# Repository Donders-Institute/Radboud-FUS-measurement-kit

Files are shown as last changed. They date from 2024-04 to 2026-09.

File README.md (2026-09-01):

# Radboud FUS measurement kit

<div align="center">
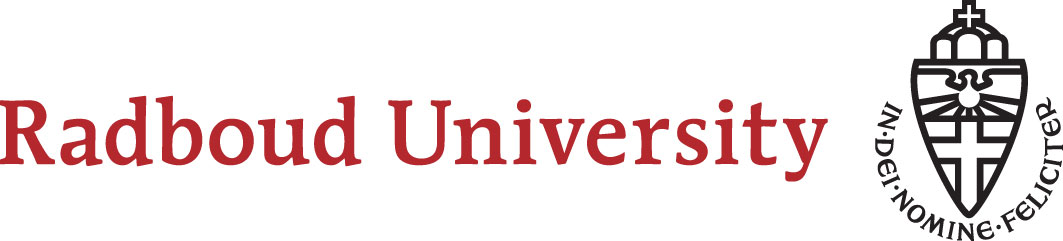
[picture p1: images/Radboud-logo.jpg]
ru_logo
  

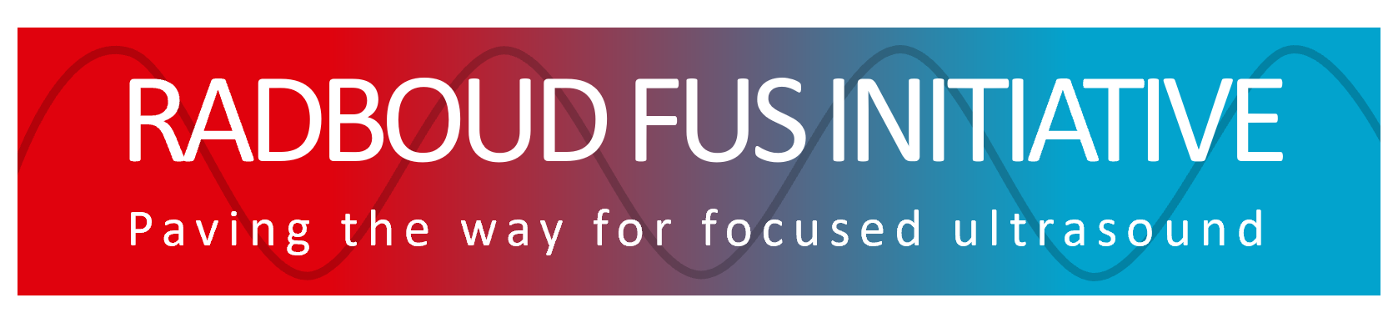
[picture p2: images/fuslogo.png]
fus_logo
  

  igt_logo
  
</div>

https://github.com/user-attachments/assets/676b7667-6fb5-469c-bd78-fa9b3e943115

<div align="center">
  
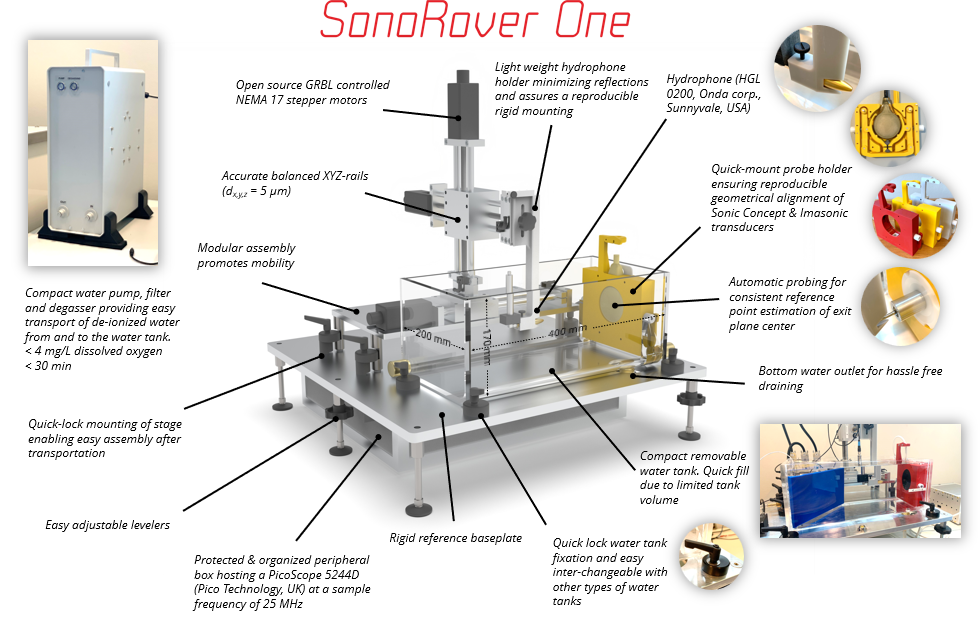
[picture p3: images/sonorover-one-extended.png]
sonorover-one
  
  
</div>

<!-- TABLE OF CONTENTS -->

# 📗 Table of Contents

- [📖 About the Project](#about-project)
  - [🚀 Key Features](#key-features)
  - [👥 Authors](#authors)
  - [✒️ How to cite](#how-to-cite)
- [💻 Getting Started](#getting-started)
  - [🔧 Installation](#install)
  - [🔌 Compatibility](#comp)
  - [📋 Usage](#usage)
- [📊 Data Analysis](#data-analysis)
- [🧰 Configuration](#config)
  - [⚙ Main Configuration File](#main-config)
  - [📻 How to add your own equipment](#add-equip)
- [🔭 Future Features](#future-features)
- [🤝 Contributing](#contributing)
- [📝 License](#license)

<!-- PROJECT DESCRIPTION -->

# 📖 Radboud FUS measurement kit 

(Project id: **0003429**)

**Radboud FUS measurement kit** is a comprehensive kit allowing precise hydrophone measurements of your TUS transducers for verification, characterization and monitoring overall system performance.    

This project is facilitated by the Radboud Focused Ultrasound Initiative. For more information, please visit the [website](https://www.ru.nl/en/donders-institute/research/research-facilities/focused-ultrasound-initiative-fus).

**⚠️ DEVELOPMENT STATUS**: This repository is currently under active development and is provided AS IS. Features may be incomplete, undergo significant changes, or contain bugs. Use at your own discretion.

<!-- Features -->

## 🚀 Key Features 

- **Comprehensive Measurement Solution:** Complete hardware and software package for ultrasound field characterization
- **High Precision Hydrophone Measurements:** Accurate characterization of acoustic parameters and beam profiles
- **Modular, Extensible Architecture:** Easily add new equipment with standardized interfaces
- **Seamless Hardware Integration:** Compatible with multiple driving systems, transducers, and measurement devices
- **Automated Acoustical Alignment:** Precise determination of the acoustical axis for optimal measurements
- **Open-Source Software:** Fully transparent, customizable codebase with no licensing costs
- **Complementary Data Analysis Tools:** Export and analyze measurement data with included utilities

<p align="right">(<a href="#readme-top">back to top</a>)</p>

<!-- AUTHORS -->

## 👥 Authors 

👤 **[Margely Cornelissen](https://www.ru.nl/en/people/cornelissen-m), [FUS Centre](https://www.ru.nl/en/donders-institute/research/research-facilities/focused-ultrasound-initiative-fus), Radboud University**

- GitHub: [@MaCuinea](https://github.com/MaCuinea)
- [LinkedIn](https://linkedin.com/in/margely-cornelissen)

👤 **[Stein Fekkes](https://www.ru.nl/en/people/fekkes-s), [FUS Centre](https://www.ru.nl/en/donders-institute/research/research-facilities/focused-ultrasound-initiative-fus), Radboud University**

- GitHub: [@StefFek-GIT](https://github.com/StefFek-GIT)
- [LinkedIn](https://linkedin.com/in/sfekkes)

👤 **Erik Dumont, [Image Guided Therapy (IGT)](http://www.imageguidedtherapy.com/)**
- GitHub: [@erikdumontigt](https://github.com/erikdumontigt)
- [LinkedIn](https://linkedin.com/in/erik-dumont-986a814)

👤 **Twan de Bruin, Technical Support Group, Donders Centre for Cognition, Radboud University**

👤 **Sibrecht Bouwstra, Technical Support Group, Donders Centre for Cognition, Radboud University**

👤 **Jan Menssen, Medical Ultrasound Imaging Center, Radboud University Medical Center**

👤 **Norbert Hermesdorf, Technical Support Group, Donders Centre for Cognition, Radboud University**

👤 **Eleanor Martin, Department of Medical Physics and Biomedical Engineering, University College London**

👤 **Lennart Verhagen, [FUS Centre](https://www.ru.nl/en/donders-institute/research/research-facilities/focused-ultrasound-initiative-fus), Radboud University**

<p align="right">(<a href="#readme-top">back to top</a>)</p>

## ✒️ How to cite 

If you use this kit in your research or project, please cite it as follows:

Margely Cornelissen, Stein Fekkes, Erik Dumont, Twan de Bruin, Sibrecht Bouwstra, Jan Menssen, Norbert Hermesdorf, Eleanor Martin & Lennart Verhagen (2024-2026), Radboud FUS measurement kit (version 1.3), https://doi.org/10.17605/OSF.IO/CG3AQ

<p align="right">(<a href="#readme-top">back to top</a>)</p>

<!-- GETTING STARTED -->

# 💻 Getting Started 

## 🔧 Installation 

### Hardware

The hardware files are stored as native solidworks files and as step format. The main assembly file: W0003510-00-01-SonoRover One.SLDASM will contain all references to part files and subassemblies. For detailed assembly instructions, refer to the [Setup Manual](/SonoRover%20One/hardware/Documentation/SonoRover%20One%20Setup%20manual%20V0_8.pdf).

### Software

#### System Architecture

Before diving into the installation, it is helpful to understand how the SonoRover One software is structured. The SonoRover One software is built on top of the standardized [Radboud FUS driving system software package](https://github.com/Donders-Institute/Radboud-FUS-driving-system-software). 

<br /> 
<div align="center">
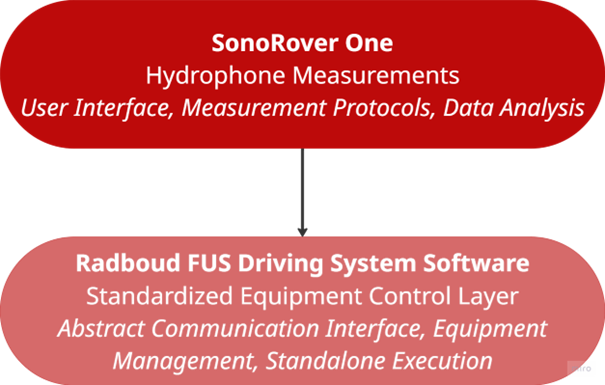
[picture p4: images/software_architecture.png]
Software Architecture
  
</div>

<br /> 

This modular approach provides:

- **Equipment Flexibility**: Easily incorporate new equipment with different communication protocols
- **Centralized Updates**: Core driving functionality can be updated independently
- **Consistent Interface**: Uniform interaction with diverse hardware components
- **Dual-Use Capability**: The same equipment configurations work in both standalone experiments and hydrophone measurements

#### Important Note

**This package is developed specifically for Windows operating systems.** While it might work in other environments with some modifications, full support is provided only for Windows.

#### Installation Steps

1. **Clone the Repository**\
   You can clone this repository using either:

   - **Git Terminal**
     ```sh
     cd my-folder
     git clone git@github.com:Donders-Institute/Radboud-FUS-measurement-kit.git
     ```

   - **GitHub Desktop**
     1. Click on 'Current repository'
     2. Click on 'Add' and select 'Clone repository...'
     3. Choose 'URL' and paste the following repository URL: [https://github.com/Donders-Institute/Radboud-FUS-measurement-kit.git](https://github.com/Donders-Institute/Radboud-FUS-measurement-kit.git)
     4. Choose your desired folder and clone the repository

2. **Download Python 3.10**\
Ensure you have Python 3.10 installed and accessible from your command line. If Python is not installed, download it from the [official Python website](https://www.python.org/downloads/release/python-31011/). It is not necessary to add Python to your system's PATH during installation, as virtual environments allow you to manage and switch between Python versions without affecting other projects or code outside the environment.

	<br /> 
	<div align="center">
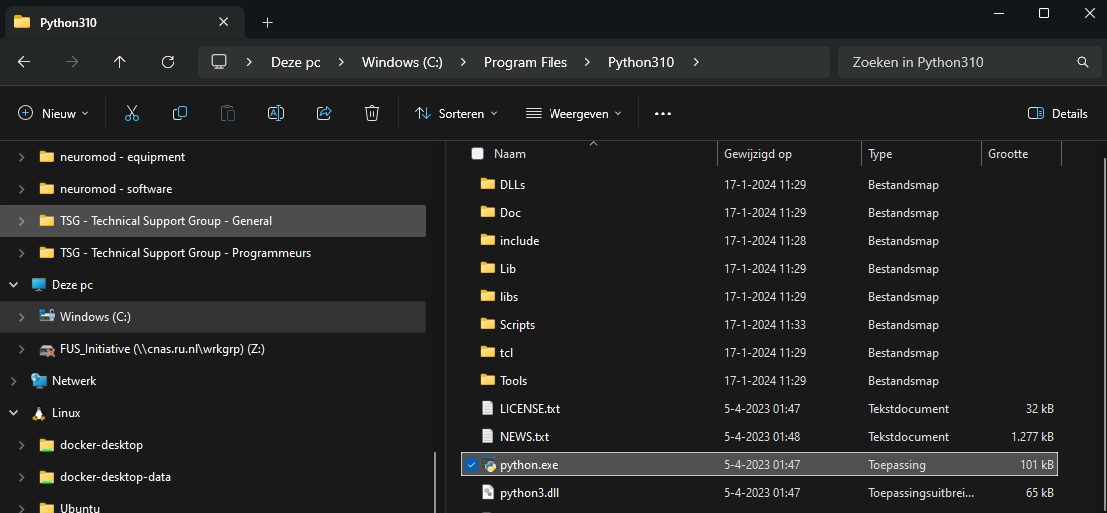
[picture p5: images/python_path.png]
python_path
	  
	</div>
	
	<br /> 

	**Note**: The script assumes that Python 3.10 is installed. If you have a different version, make sure to adjust the script accordingly or install Python 3.10.

3. **Create and setup a virtual environment**\
Open your command prompt and run the following batch file to set up the virtual environment and install the necessary dependencies. You can use input parameters to customize the environment name or directory, or Python interpreter location. You can use the default values or specify only the parameters you need by leaving others blank with "".

	```
	cd your_directory_with_cloned_repository
	create_venv.bat "[PYTHON_INTERPRETER_PATH]" [VENV_NAME] "[VENV_DIR]"
	```
		
	- PYTHON_INTERPRETER_PATH: Specify the path to the Python 3.10 interpreter if it is not in the default location. For example, C:\Path\To\Python310\python.exe.
	- VENV_NAME: Specify the name for the virtual environment (e.g., MyEnv). If not provided, it defaults to SONOROVER_ONE.
	- VENV_DIR: Specify the directory for the virtual environment (e.g., C:/Users/Me/Envs). If not provided, it defaults to C:/Users/{USERPROFILE}/Envs.
	
	Example:
	```
	create_venv.bat "C:\Path\To\Python310\python.exe" SONOROVER_ONE "C:/Users/Me/Envs"
	```

	The batch file will:
	- Create a virtual environment
	- Install the required Python packages and the default IDE, Spyder
	- Clone the Radboud FUS driving system software repository into the SonoRover One repository. **Note:** The installation script automatically clones the latest released version of the Radboud FUS driving system software. If you need a different version (e.g., development branch or specific release), please refer to the [Radboud FUS driving system software README](https://github.com/Donders-Institute/Radboud-FUS-driving-system-software/blob/release/README.md) for manual installation instructions.
	- Install the Radboud FUS driving system software package

4. **Verify Installation**\
After running the batch file, ensure that the virtual environment and dependencies are installed. You can verify this by:

	- Checking for the virtual environment folder in your VENV_DIR directory.
		<div align="left">
		  verify_venv
		</div>
	
	- Confirming that the fus_driving_systems package is installed in the virtual environment site-packages folder: VENV_DIR/VENV_NAME/Lib/site-packages/.
		<div align="center">
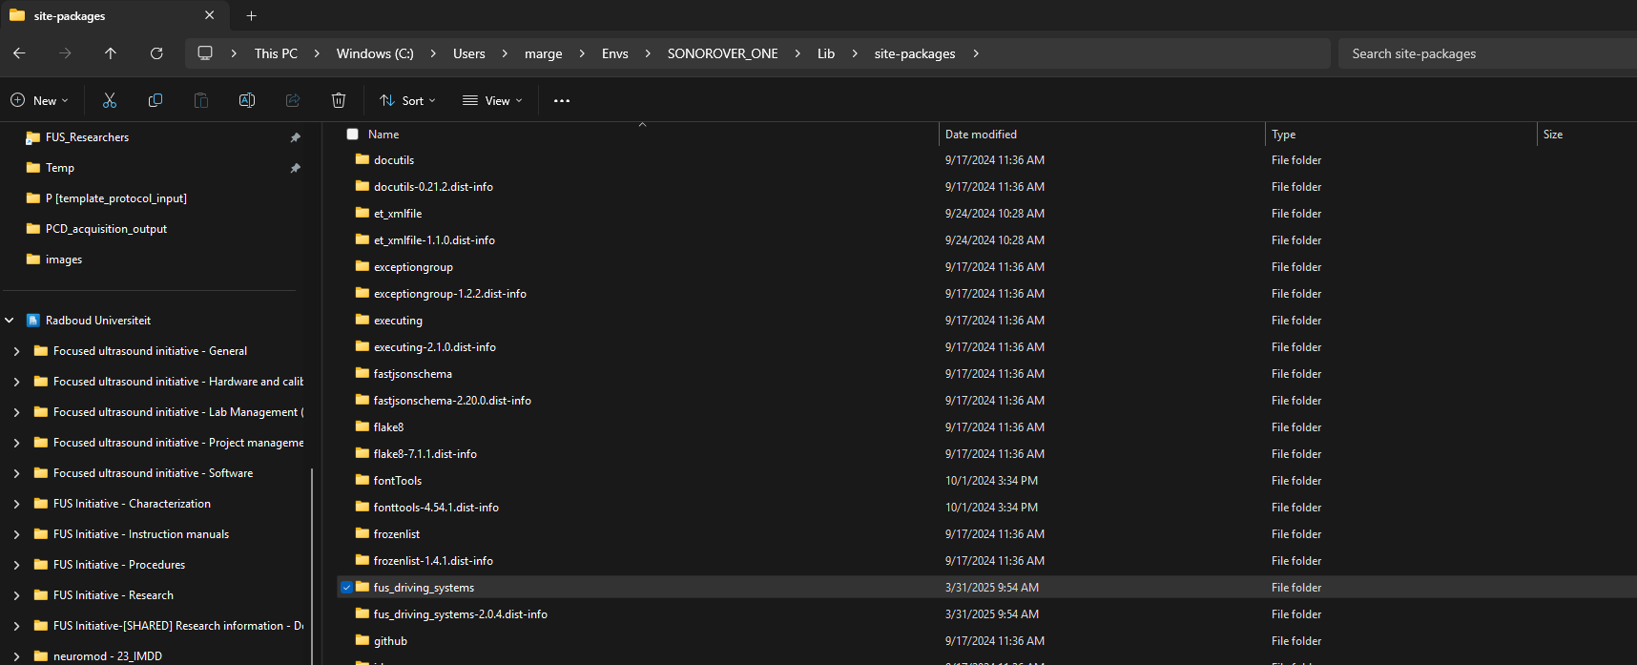
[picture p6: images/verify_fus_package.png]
verify_fus_package
		  
		</div>

#### Troubleshooting
If you encounter issues with the batch file not being recognized or errors during execution, ensure that:

- The batch file has the correct permissions to execute.
- The repository has been cloned correctly and contains the necessary files.

<p align="right">(<a href="#readme-top">back to top</a>)</p>

## 🔌 Compatibility 

The table below outlines compatibility between different versions of the Radboud FUS driving system software and the SonoRover One software.

| SonoRover One Version | Radboud FDS Compatibility | Python Version |
|---|---|---|
| 1.2 (Current) | Radboud FDS v2.1 | 3.10  |
| 1.3 (Current) | Radboud FDS v2.2+ | 3.10  |

Note:
- Newest version is **not compatible** with Radboud FDS v2.1 or lower  
- Tested with **Python 3.10**

<p align="right">(<a href="#readme-top">back to top</a>)</p>

## 📋 Usage 

### Hardware
For usage instructions, refer to paragraph 3.2 *Pre-measurement setup instructions* of the [Setup Manual](/SonoRover%20One/hardware/Documentation/SonoRover%20One%20Setup%20manual%20V0_8.pdf).

### Software

*Step 1: Activate your environment*\
With all dependencies installed, activate your environment in your command prompt. 

```
call [VENV_PATH]\Scripts\activate
```

*Step 2: Install an IDE*\
While your virtual environment is activated, you can install any IDE of your choice. Spyder is pre-installed by default. To install another IDE, run:

```
pip install [IDE]
```

*Step 3: Launch the IDE*\
After installing your IDE, you can launch it directly from the command line while the virtual environment is activated. For Spyder, enter:

```
spyder
```

#### Activate your virtual environment and launch the IDE at once
To simplify the process of activating the virtual environment and launching your IDE, you can use the provided [batch script](start_venv_and_ide.bat).

How to use the script:
1. Ensure that start_env_and_ide.bat is located in a convenient location, such as the root directory of your project or your desktop.
2. Run the script in one of the following ways:
	- Open start_venv_and_ide.bat in a text editor and modify the VENV_PATH and IDE variables directly if you prefer not to use command-line arguments. To run the .bat file, just double-click it.
	- Using the command prompt:
		```
		start_venv_and_ide.bat [VENV_PATH] [IDE]
		```
		- VENV_PATH: Specify the path to the virtual environment (e.g., C:/Users/Me/Envs/MyEnv). If not provided, it defaults to C:/Users/{USERPROFILE}/Envs/SONOROVER_ONE.
		- IDE: Specify the python interpreter. If not provided, it defaults to spyder.

#### Starting the Software
The SonoRover One software provides a graphical interface for hydrophone measurements. This section guides you through using the software.

The primary script is [main](/SonoRover%20One/software/src/main.py). Running this script launches the main GUI:

<div align="left">
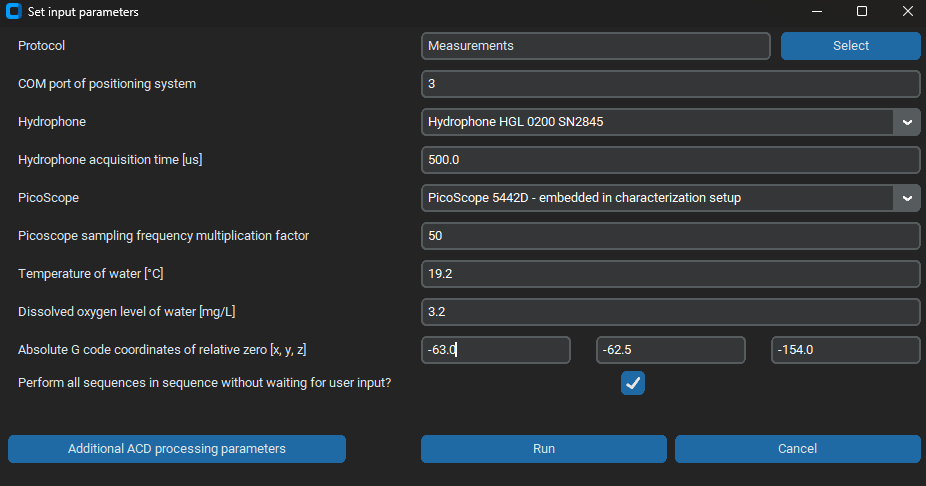
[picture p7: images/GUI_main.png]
gui_main
  
</div>

##### Main GUI Parameters

The main interface allows you to configure the following parameters:

1. **Protocol**: Opens a dialog to select a measurement protocol
2. **COM port of positioning system**: Select the communication port for the positioning system
3. **Hydrophone**: Select the hydrophone model to use for measurements
4. **Hydrophone acquisition time [us]**: Set the signal acquisition duration per grid point
5. **PicoScope**: Select the PicoScope model for signal acquisition
6. **Picoscope sampling frequency multiplication factor**: Set the sampling rate (minimum factor is 2)
7. **Temperature of water [C]**: Record water temperature for post-processing
8. **Dissolved oxygen level of water [mg/L]**: Record for documentation purposes
9. **Absolute G code coordinates of relative zero**: Set coordinates for the reference zero point. This initially uses the mechanical alignment coordinates as its basis. After completing an acoustical alignment, the system updates the x- and y-coordinates to match the measured acoustical axis at the specified z-coordinate.
10. **Perform all protocols in sequence without waiting for user input?**: Toggle automatic sequence execution

##### Protocol Selection

When you click the "Select" button, a dialog appears with system setup parameters:

- **US Driving System**: Select the ultrasound system
- **COM port of US driving system**: Required for Sonic Concepts systems
- **Transducer**: Select the transducer model
- **Operating frequency [kHz]**: Set the operating frequency of the transducer

After setting these general parameters, you have to choose between two protocol options:

*Option 1: Select Protocol Excel File*

<div align="left">
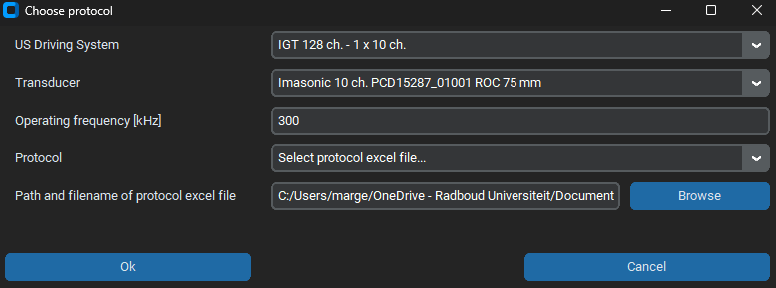
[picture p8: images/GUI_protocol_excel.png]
gui_protocol_excel
  
</div>

This option allows you to select an Excel file containing predefined measurement protocols.
- **Path and filename of protocol excel file**: Select the Excel file containing measurement protocols
  - Template available [here](SonoRover%20One/software/example%20input/protocol%20template/template_protocol_input.xlsx)
  - **Note**: If you modify column headers in the Excel file, update the corresponding settings in the configuration file

The protocol Excel file contains the following parameters for each sequence:

| Parameter | Description |
|---|---|
| **Sequence number** | Sequential number (1 to N) |
| **Tag** | Additional information saved in output .ini file |
| **Modulation** | Select from Rectangular - no ramping, Linear, or Tukey ramp shapes |
| **Ramp duration [us]** | Duration of the ramp |
| **Pulse duration [us]** | Duration of each pulse |
| **Pulse Repetition Interval [ms]** | Total pulse period including ramping, pulse duration and off-time between two pulses |
| **Power parameter** | Select appropriate power parameter for your system:<br>- IGT: Amplitude [%], Voltage [V], or Max. pressure [MPa]<br>- Sonic Concepts: Global power [mW] |
| **Corresponding value** | Value for the selected power parameter |
| **Focus definition** | Define focus relative to exit plane or mid bowl |
| **Corresponding value** | Value for the selected focus parameter |
| **(De)phase array [degree]** | For IGT systems only: option to create sham conditions |
| **Coordinates source** | Choose between coordinate Excel file or parameter-defined grid |

If using a **coordinate Excel file**:
- Provide path to the file (examples [here](SonoRover%20One/software/example%20input/coordinate%20templates))
- Allows flexible grid point arrangement
- **Note**: Headers must match configuration settings

If using **parameters**:
- **max. ± x/y/z [mm]**: Maximum movement in each direction relative to zero point
- **direction_slices/rows/columns**: Direction settings (refer to [template](SonoRover%20One/software/example%20input/protocol%20template/template_protocol_input.xlsx))
- **step_size_x/y/z [mm]**: Grid size in each direction

*Option 2: Acoustical Alignment*

<div align="left">
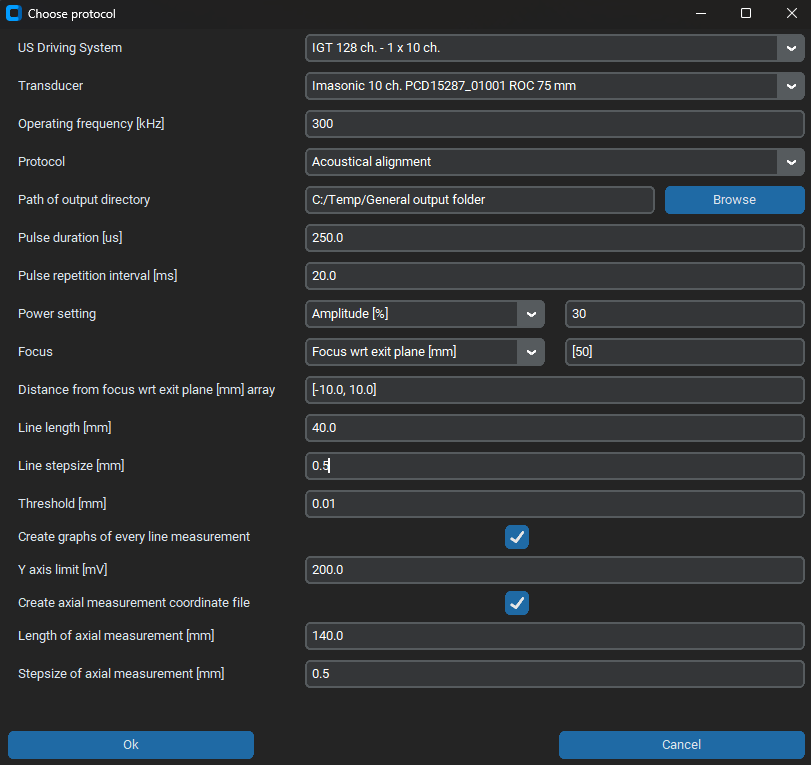
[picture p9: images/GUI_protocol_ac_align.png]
gui_protocol_ac_align
  
</div>

<br />

This option performs an acoustical alignment to determine the acoustical axis through iterative measurements. The process finds the center of mass of RMS voltage values per defined location and calculates the direction vector with corresponding azimuth and elevation.

Parameters include:

| Parameter | Description |
|---|---|
| **Path of output directory** | Directory for saving output and logging files |
| **Pulse duration [us]** | Duration of each pulse |
| **Pulse Repetition Interval [ms]** | Total pulse period including ramping, pulse duration and off-time between two pulses |
| **Power setting** | Appropriate power parameter for your system |
| **Focus** | Define focus relative to exit plane or mid bowl |
| **Distance from focus wrt exit plane [mm] array** | Distances from the focus wrt exit plane to acquire middle points (negative = toward transducer) |
| **Line length [mm]** | Length of each direction scan |
| **Line stepsize [mm]** | Step size of direction scan |
| **Threshold [mm]** | Convergence threshold for determining middle points |
| **Create graphs** | Toggle creation of direction scan graphs |
| **Y axis limit [mV]** | Y-axis limit for RMS value display |
| **Create axial measurement file** | Toggle creation of coordinate file for axial scan |
| **Length of axial measurement [mm]** | Define length for axial scan |
| **Stepsize of axial measurement [mm]** | Define step size for axial scan |

**Note:** The coordinate file generated by the acoustical alignment can be used as input for a subsequent measurement. This allows you to perform an axial scan along the precisely determined acoustical axis, rather than along a mechanically aligned axis.

#### Running Measurements

After configuring all parameters, click "OK" to start the characterization process. The software will:

1. Display dialog screens to verify equipment connections
2. Create log files in the same directory as the protocol file
3. Create an output folder for measurement results
4. Begin the measurement sequence

If you selected "Perform all protocols in sequence without waiting for user input," the software will automatically proceed through all sequences defined in the protocol file.

#### Important Notes

- When performing acoustical alignment, the found X and Y values will overwrite the initial absolute G code coordinates
- Ensure the PicoScope software is not connected to the PicoScope during measurements
- Ensure Universal Gcode Sender is not connected to the positioning system

<p align="right">(<a href="#readme-top">back to top</a>)</p>

# 📊 Data Analysis 

For usage instructions, refer to the [User Manual SonoRover One Data Analysis](/SonoRover%20One/hardware/Documentation/SonoRover%20One%20Data%20Analysis%20User%20manual%20V0_8.pdf).

<p align="right">(<a href="#readme-top">back to top</a>)</p>

<!-- CONFIGURATION -->

# 🧰 Configuration 

The SonoRover One software uses a comprehensive configuration system to control its behavior. This section explains how to modify configuration settings and add new equipment to the system.

## ⚙️ Main Configuration File 

The main configuration file is located at [here](SonoRover%20One/software/src/config/characterization_config.ini). You can either modify this file directly or use the provided [create_config.py](SonoRover%20One/software/src/config/create_config.py) script to regenerate it with your changes.

### General Settings

```ini
[General]
maximum number of output filename = 1000
```

- **maximum number of output filename**: Sets the maximum number of sequentially numbered output files (1000 by default). When multiple files share the same base name, the system appends numbers (1, 2, 3...) until this limit is reached.

### Logging Configuration

```ini
[Logging]
logger name = SonoRover_One
timestamp format = %Y-%m-%d_%H-%M-%S
log level console = WARNING
log level file = INFO
initial part of log filename = log_
```

- **logger name**: Identifier for the logger instance
- **timestamp format**: Format used for timestamps in logs 
- **log level console**: Minimum severity level displayed in console (INFO, DEBUG, WARNING, ERROR, CRITICAL)
- **log level file**: Minimum severity level saved to log files (INFO, DEBUG, WARNING, ERROR, CRITICAL)
- **initial part of log filename**: Prefix for all generated log files

### Path and Directory Settings

```ini
[Characterization]
path of input parameters cache = config//characterization_input_cache.ini
cache date format = %Y/%m/%d
temporary output path = C:\Temp\General output folder
temporary logging path = C:\Temp\General output folder\logs
default protocol directory = //ru.nl//WrkGrp//FUS_Hub//Hydrophone measurements//Measurements
default output directory = //ru.nl//WrkGrp//FUS_Hub//Hydrophone measurements//Measurements//2024//General output folder
```

- **path of input parameters cache**: Location where user input parameters are cached
- **cache date format**: Date format used in the cache file
- **temporary output path**: Directory that temporarily stores measurement output. This approach allows data to be transferred to an online folder after acquisition is complete, without slowing down the measurement process. 
- **temporary logging path**: Directory that temporarily stores logging. This approach allows data to be transferred to an online folder after acquisition is complete, without slowing down the measurement process. 
- **default protocol directory**: Default location for measurement protocols displayed in GUI
- **default output directory**: Default location for saving measurement results displayed in GUI

### GUI Configuration

```ini
protocol_dialog.n_ac_align_rows = 14
protocol_dialog.stay_topmost_in_ms = 5000
input_dialog.stay_topmost_in_ms = 5000
acd_dialog.stay_topmost_in_ms = 5000
```

- **protocol_dialog.n_ac_align_rows**: Number of rows in acoustical alignment section
- **protocol_dialog.stay_topmost_in_ms**: Duration for keeping protocol dialog on top (5000ms)
- **input_dialog.stay_topmost_in_ms**: Duration for keeping input dialog on top (5000ms)
- **acd_dialog.stay_topmost_in_ms**: Duration for keeping ACD dialog on top (5000ms)

### Output Configuration

```ini
output_name_suffix = output_data
ac_align.output_name_suffix = output_data
ac_align.axis_suffix = acoustical_axis
ac_align.additional_x_lim = 15
```

- **output_name_suffix**: Suffix for output data files
- **ac_align.output_name_suffix**: Suffix for acoustical alignment output files
- **ac_align.axis_suffix**: Suffix for acoustical axis plots
- **ac_align.additional_x_lim**: Additional space added to X-axis limit of acoustical alignment plot (15 mm)

### Acquisition Equipment Configuration

```ini
picoscope.reacquire_attempts = 5
picoscope.resolution = DR_14BIT
picoscope.channel = A
picoscope.range = RANGE_500mV
picoscope.coupling = DC
picoscope.probe_multi = x1
picoscope.trigger_threshold_v = 0.5
pos_sys.reacquire_attempts = 5
```

- **picoscope.reacquire_attempts**: Number of retry attempts for acquisition (5)
- **picoscope.resolution**: Hardware resolution during acquisition (DR_14BIT)
- **picoscope.channel**: Input channel for hydrophone connection (A)
- **picoscope.range**: Voltage range setting (RANGE_500mV)
- **picoscope.coupling**: Input coupling mode (DC)
- **picoscope.probe_multi**: Probe attenuation multiplier (x1)
- **picoscope.trigger_threshold_v**: Trigger threshold voltage (0.5V)
- **pos_sys.reacquire_attempts**: Number of attempts to reconnect to positioning system (5)

### Excel Column Definitions

The configuration file defines column names used in coordinate and protocol Excel files. If you modify the headers in your Excel templates, you will need to update these settings to match.

```ini
coord_excel_columns.meas_num = Measurement number
coord_excel_columns.clus_num = Cluster number
coord_excel_columns.ind_num = Indices number
# ... more column definitions
```

```ini
prot_excel_columns.seq_num = Sequence number
prot_excel_columns.tag = Tag
prot_excel_columns.dephasing = (De)phase array [degree] (None = no (de)phasing) ONLY FOR IGT DS
# ... more column definitions
```

### Default Values
The configuration file contains default values for the GUI inputs. These values are loaded when the software starts and are used as initial values in the interface.

```ini
default.acq_time_us = 500
default.sampl_freq_multi = 50
default.pos_com_port = COM3
default.temp = 
default.dis_oxy = 
default.x_coord_zero = -62.2
default.y_coord_zero = -60.6
default.z_coord_zero = -155.528
default.perform_all_seqs = True
# ... more default settings
```

You can modify these values to match your typical usage patterns. Equipment-specific defaults (like default driving system) are determined by the Radboud-FUS-driving-system-software configuration.

### Messages
The configuration file also defines various messages displayed to users during the measurement process:

```ini
disconnection message = Ensure the following: 
     - PicoScope software is not connected to the PicoScope in use. 
     - Universal Gcode Sender is not connected to the positioning system.
continue acquisition message = Continue acquisition with the following sequence: 
```

These messages can be customized to provide clearer instructions to users of your system.

<p align="right">(<a href="#readme-top">back to top</a>)</p>

## 📻 Adding Your Own Equipment 

### FUS Equipment

To add your own FUS equipment, refer to the [Radboud-FUS-driving-system-software README](https://github.com/Donders-Institute/Radboud-FUS-driving-system-software), as the SonoRover One software uses this as a plugin for controlling FUS equipment. 

### Hydrophone

The current software version supports the following hydrophones:
- HGL 0200 SN2845
- HGL 0200 SN3030
- HNR 0500 SN2439

To add a new hydrophone:

#### Step 1: Add to Equipment Section
Add your hydrophone to the configuration file under the `[Characterization.Equipment]` section:

```ini
[Characterization.Equipment]
hydrophones = HGL 0200 SN2845
    HGL 0200 SN3030
    HNR 0500 SN2439
    YOUR-MODEL-NAME  # Add your hydrophone model here
```

#### Step 2: Add Specific Equipment Settings
Create a new section for your hydrophone model:

```ini
[Characterization.Equipment.YOUR-MODEL-NAME]
name = Hydrophone YOUR-MODEL-NAME
sensitivity (v/pa) datasheet = config//hydrophones//YOUR-MODEL-NAME Calibration datasheet.xlsx
```

The hydrophone identifier must match one of the identifiers defined in the  `[Characterization.Equipment]` section under *hydrophones*. The `name` parameter is displayed in the GUI.

#### Step 3: Create a Sensitivity Datasheet
Create a new datasheet in the [SonoRover One\software\src\config\hydrophones](SonoRover%20One/software/src/config/hydrophones) folder, using one of the existing files as a template. This file contains the frequency-sensitivity mapping for your hydrophone.

If sensitivity values are not known, set all values to zero, but note that measurement output values will be incorrect. 

### PicoScope

Currently, only PicoScope oscilloscopes are supported. The software supports these models:
- 5442D
- 5442A
- 5244D 

To add a new PicoScope model:

#### Step 1: Extend pico.py
Extend the [pico.py](SonoRover%20One/software/src/backend/pico.py) script with a class for your PicoScope model:

```python
class ScopeYOUR_MODEL_ID(Scope5000):
    """
    Model YOUR-MODEL-ID description
    """
    def __init__(self):
        Scope5000.__init__(self)
        self.model = ModelSpecification("YOUR-MODEL-ID", "PS5000a.dll", "ps5000a")
        self.model.handle = None
        self.model.channelCount = 2
        self.model.maxGeneratorFrequency = 20e6  # 20 MHz and min = 0
        self.model.maxTimeBase = (2 ** 32) - 1
        self.model.maxLowSamplingRate = 125e6
        self.model.maxHighSamplingRate = 1e9
        self.model.EXTRange = Range.RANGE_5V
        self.model.EXTmaxADC = 32767  # PS5000A_EXT_MAX_VALUE
        # self.model.resolution = None  # set in OpenUnit
        self._clearSettings()
```

Then modify the `getScope` function to include your model:

```python
def getScope(modelName):
    """
    Returns an instance of the Scope object for the requested model.
    """
    if modelName.startswith("5242"):
        return Scope5242A()
    elif modelName.startswith("5442"):
        return Scope5442A()
    elif modelName.startswith("5244"):
        return Scope5244D()
    elif modelName.startswith("YOUR-MODEL-ID"):  # Add your model check
        return ScopeYOUR_MODEL_ID()
    raise PicoError("Unsupported model (%s)." % modelName)
```

#### Step 2: Add to Equipment Section
Add your PicoScope to the configuration file under the `[Characterization.Equipment]` section:

```ini
[Characterization.Equipment]
picoscopes = 5442D
    5242D
    5442A
    5244D
    YOUR-MODEL-NAME  # Add your PicoScope model here
```

#### Step 3: Add Specific Equipment Settings
Create a new section for your PicoScope model:

```ini
[Characterization.Equipment.YOUR-MODEL-NAME]
name = PicoScope YOUR-MODEL-NAME
pico.py identification = YOUR-MODEL-ID
```

The `pico.py identification` parameter must match the identifier used in the `getScope` function in pico.py. The `name` parameter is displayed in the GUI.

<p align="right">(<a href="#readme-top">back to top</a>)</p>

<!-- FUTURE FEATURES -->

# 🔭 Future Features 

## Software

- [ ] Eliminate Excel dependencies through GUI expansion and restructuring
- [ ] Implement line scanning capability for faster acquisition
- [ ] Develop comprehensive unit test framework
- [ ] Add timer functionality
- [ ] Implement signal detection check before proceeding with measurements

<p align="right">(<a href="#readme-top">back to top</a>)</p>

<!-- CONTRIBUTING -->

# 🤝 Contributing 

Contributions, issues, and feature requests are welcome!

Feel free to check the [issues page](../../issues/).

If you have any questions, please feel free to reach out to us via email at fus@ru.nl.
We'd love to hear from you.

<p align="right">(<a href="#readme-top">back to top</a>)</p>

# 📝 License 

This project is [MIT](./LICENSE) licensed.

<p align="right">(<a href="#readme-top">back to top</a>)</p>

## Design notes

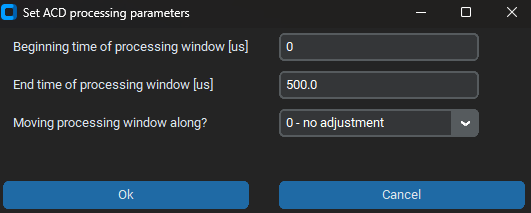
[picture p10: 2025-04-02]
images/GUI_acd.png

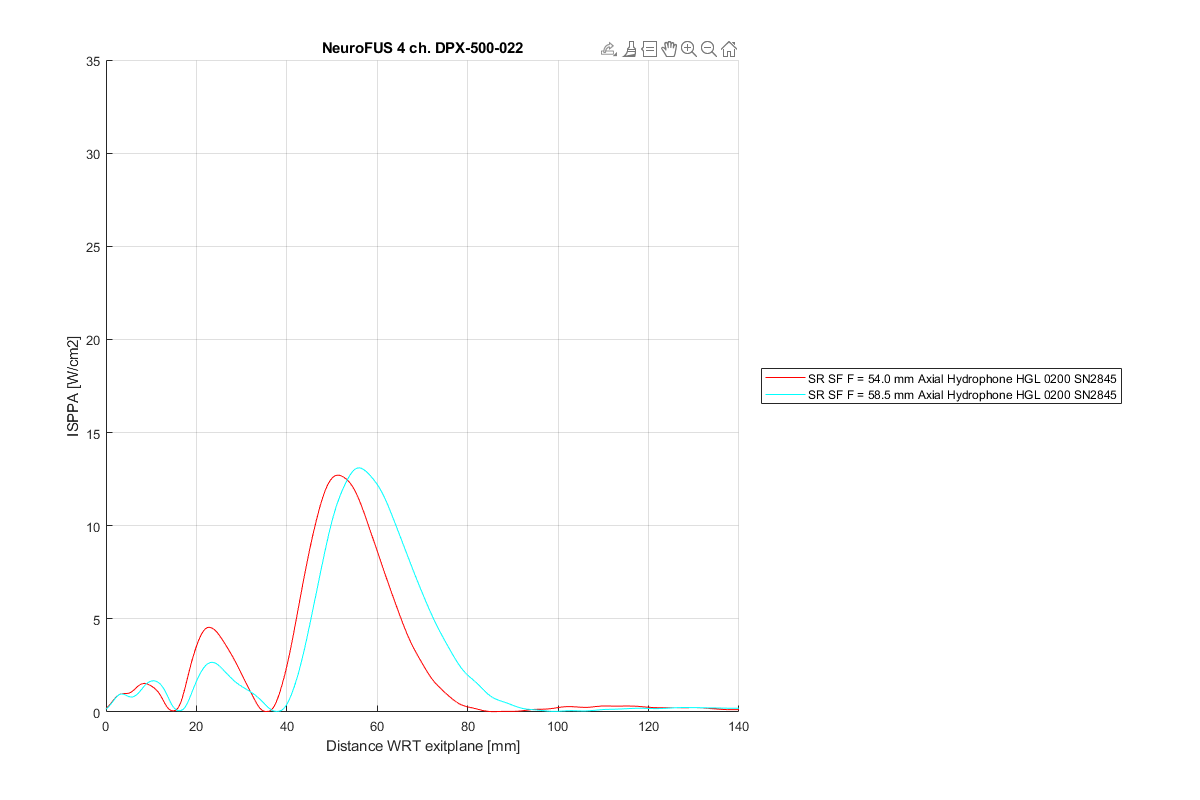
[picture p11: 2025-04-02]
SonoRover One Data Analysis/SonoRover One/DPX/postProcessing_2025-02-26_11-13-42/axialProfilesSingleView ISPPA [ NeuroFUS 4 ch. DPX-500-022.tiff

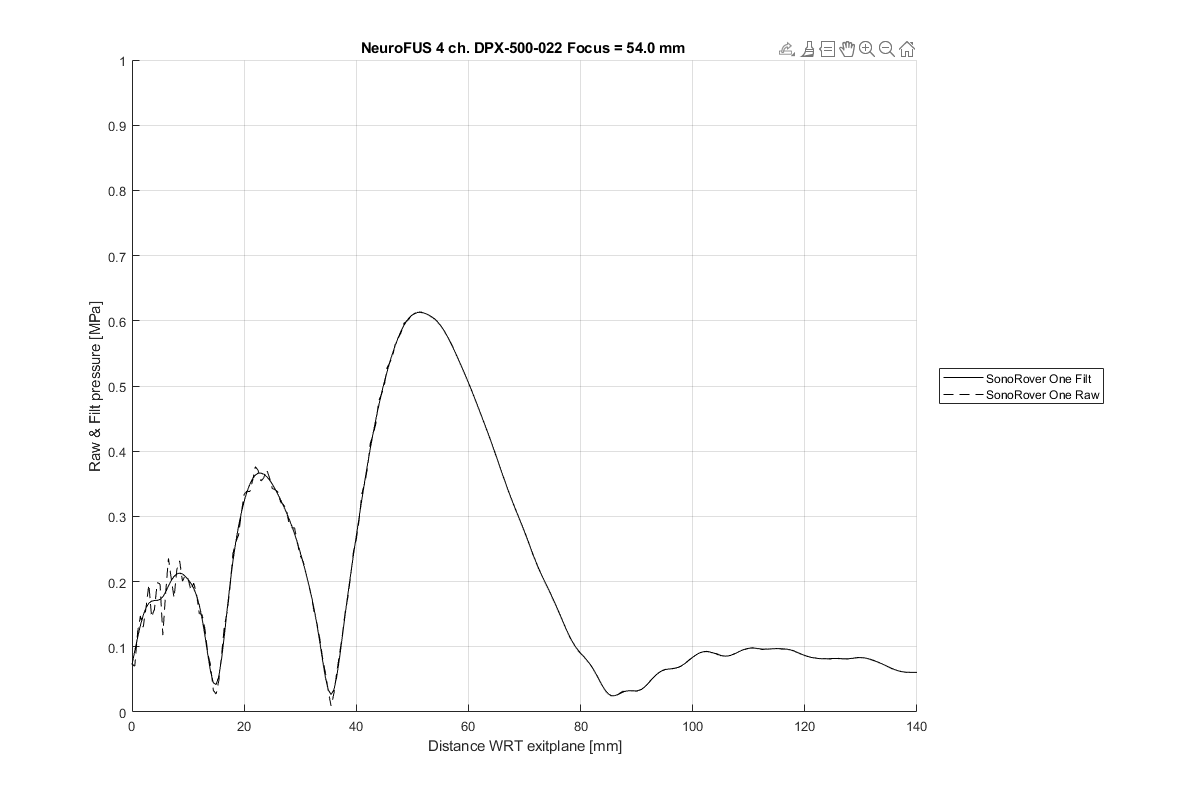
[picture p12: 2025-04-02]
SonoRover One Data Analysis/SonoRover One/DPX/postProcessing_2025-02-26_11-13-42/axialProfilesContainer Raw & F NeuroFUS 4 ch. DPX-500-022.tiff

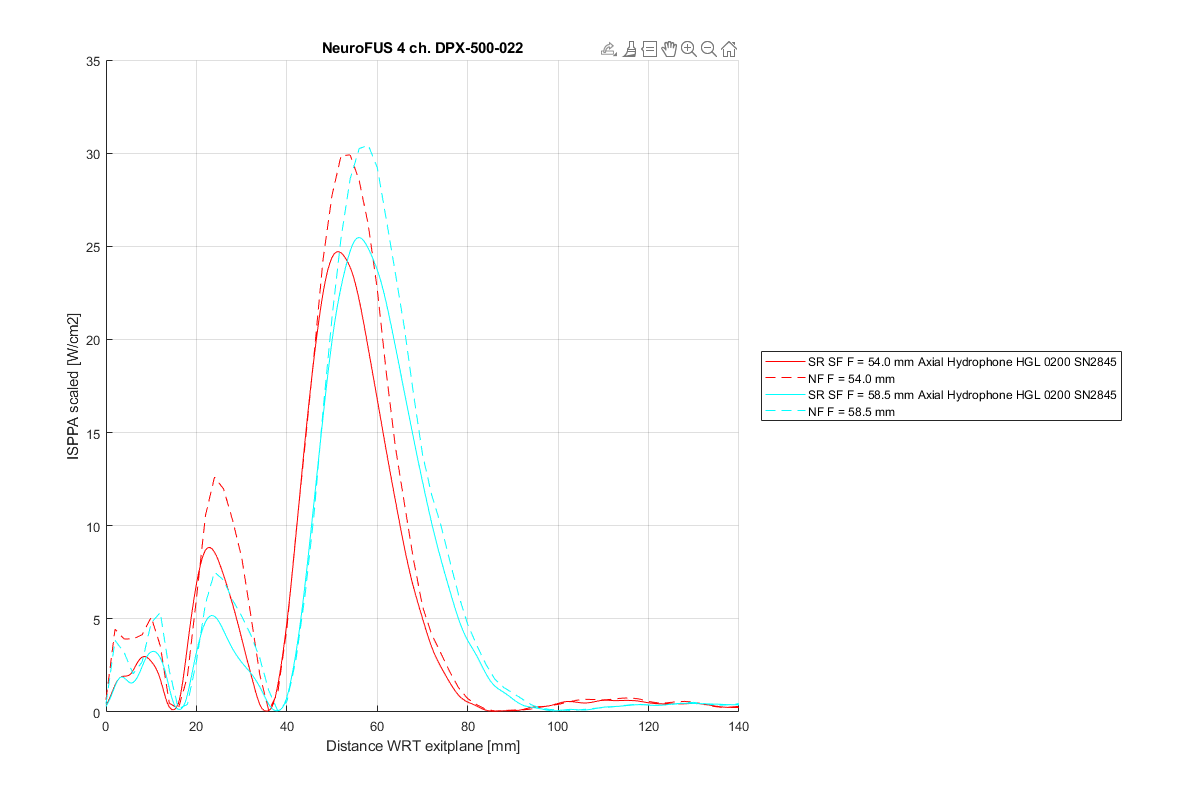
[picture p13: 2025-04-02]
SonoRover One Data Analysis/SonoRover One/DPX/postProcessing_2025-02-26_11-13-42/axialProfilesSingleView ISPPA s NeuroFUS 4 ch. DPX-500-022.tiff

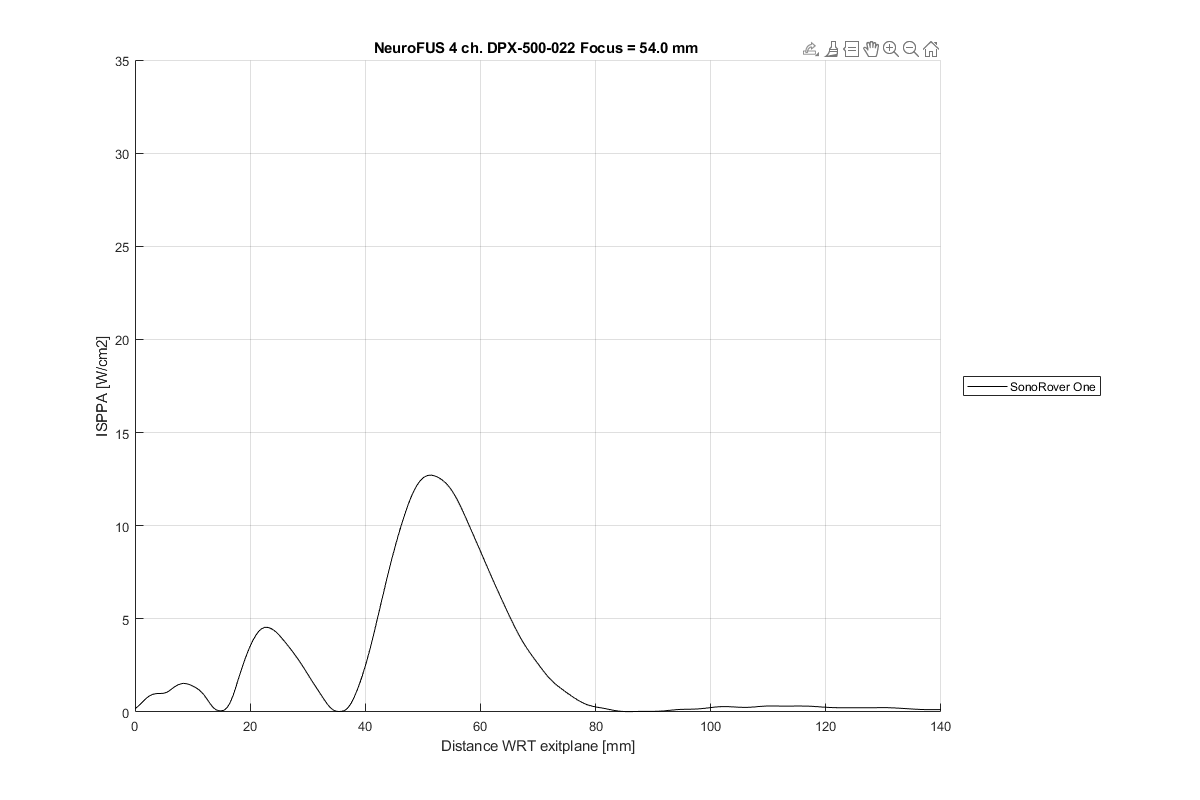
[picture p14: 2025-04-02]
SonoRover One Data Analysis/SonoRover One/DPX/postProcessing_2025-02-26_11-13-42/axialProfilesContainer ISPPA [ NeuroFUS 4 ch. DPX-500-022.tiff

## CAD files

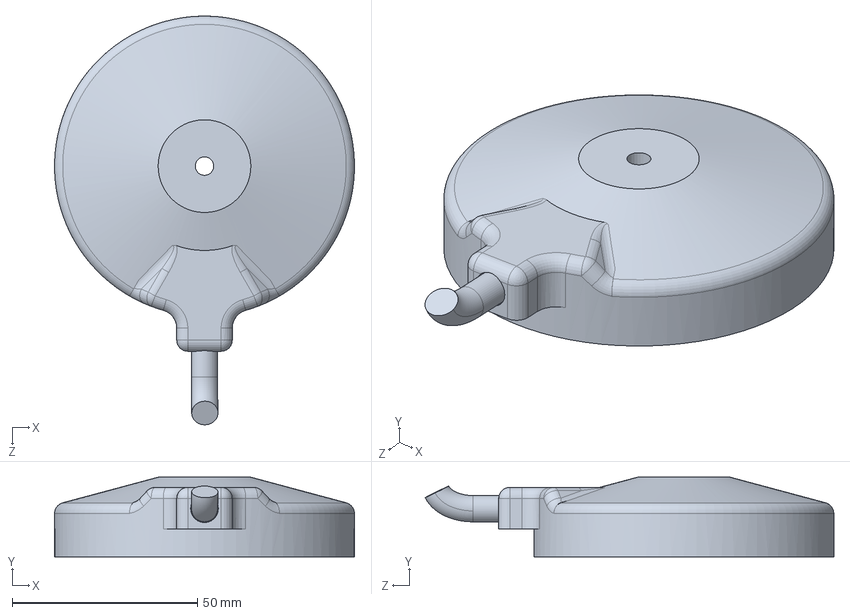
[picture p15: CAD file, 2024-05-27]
SonoRover One/hardware/SolidWorks/W0003510-012-Imasonic 15287A0100000 81.SLDPRT
81.0 x 21.5 x 110.3 mm

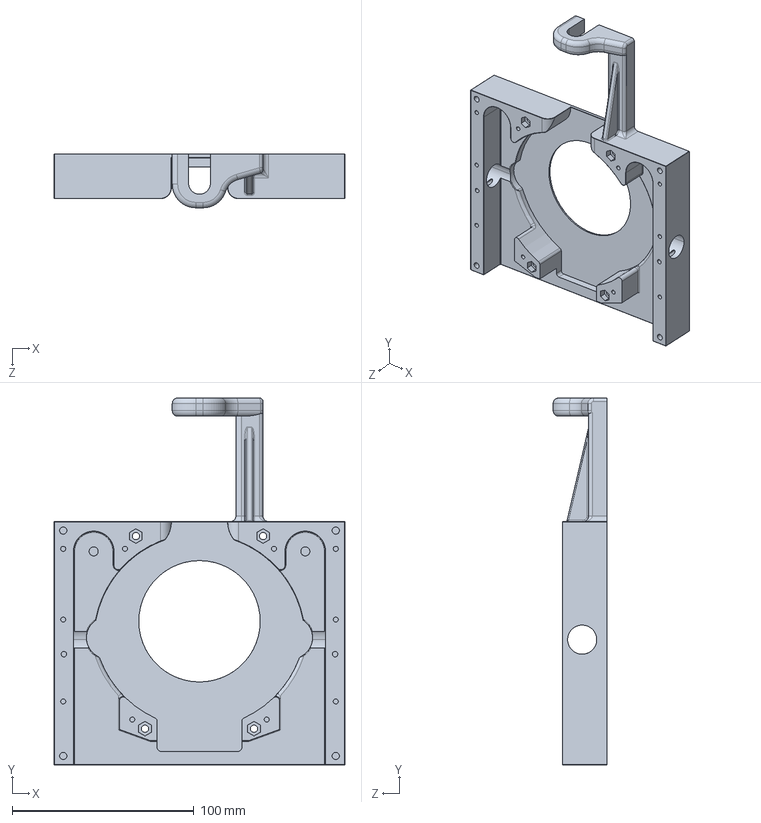
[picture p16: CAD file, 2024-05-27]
SonoRover One/hardware/Step/W0003519-001-SC-CTX-4CH-72 Tranducer front plate.STEP
160.0 x 202.0 x 29.5 mm

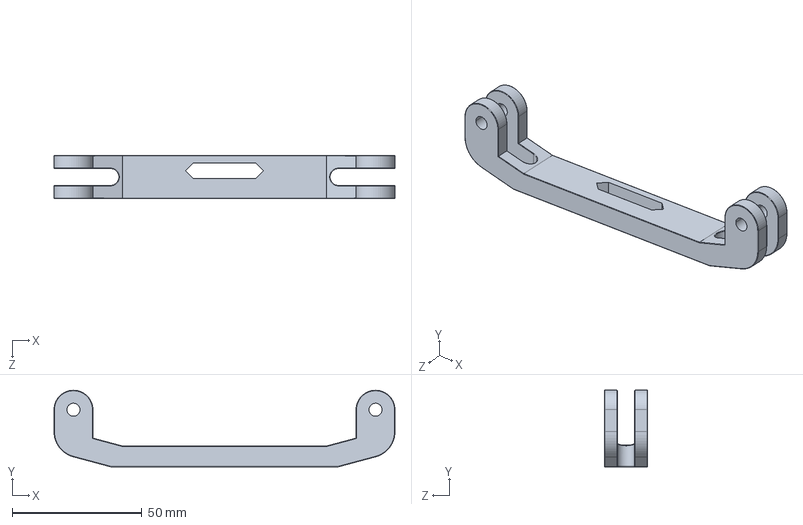
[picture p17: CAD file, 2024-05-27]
SonoRover One/hardware/Step/W0003510-007-wiggle arm54.STEP
131.5 x 29.5 x 16.7 mm

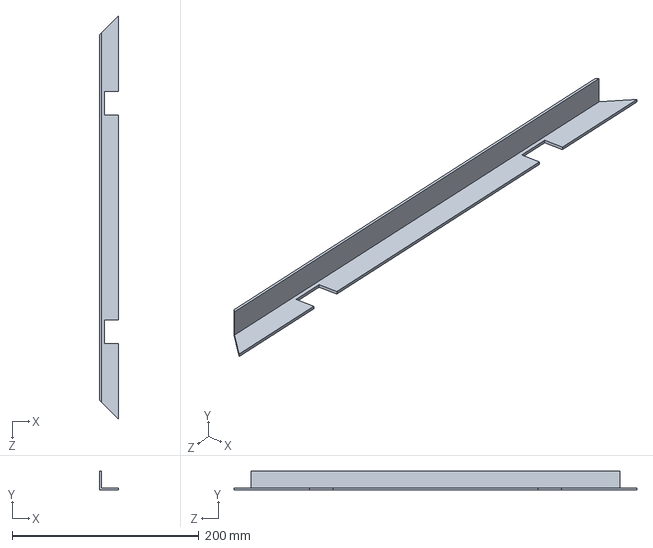
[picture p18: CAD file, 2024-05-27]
SonoRover One/hardware/Step/W0003510-69--L profiel 400.STEP
20.0 x 20.0 x 432.0 mm

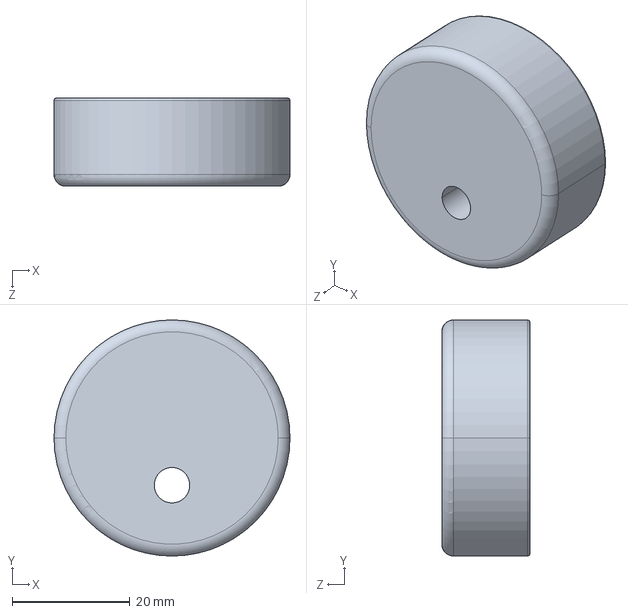
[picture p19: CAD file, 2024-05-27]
SonoRover One/hardware/Step/W0003510-53-clamping disc.STEP
40.0 x 40.0 x 15.0 mm

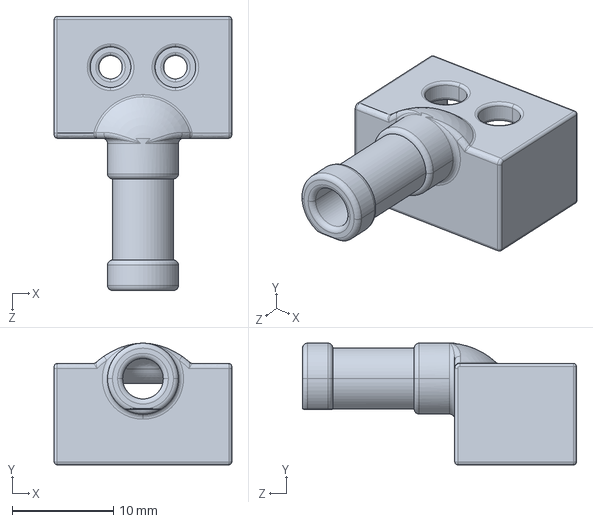
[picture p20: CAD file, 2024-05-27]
SonoRover One/hardware/Step/W0003510-74-micro switch cap.STEP
17.5 x 12.0 x 27.0 mm

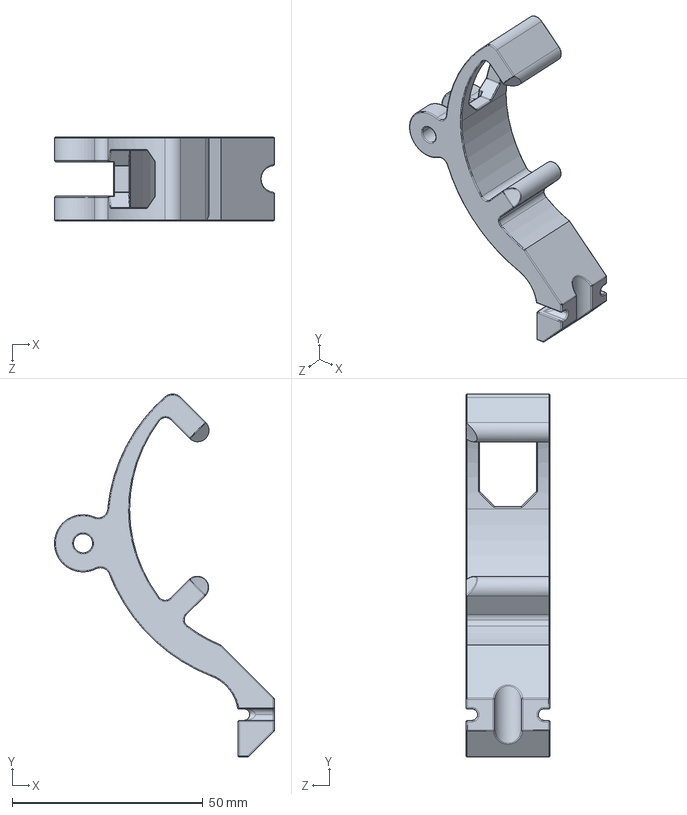
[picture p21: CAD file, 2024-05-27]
SonoRover One/hardware/Step/W0003510-004- L-middle intake54.STEP
57.7 x 95.2 x 22.0 mm

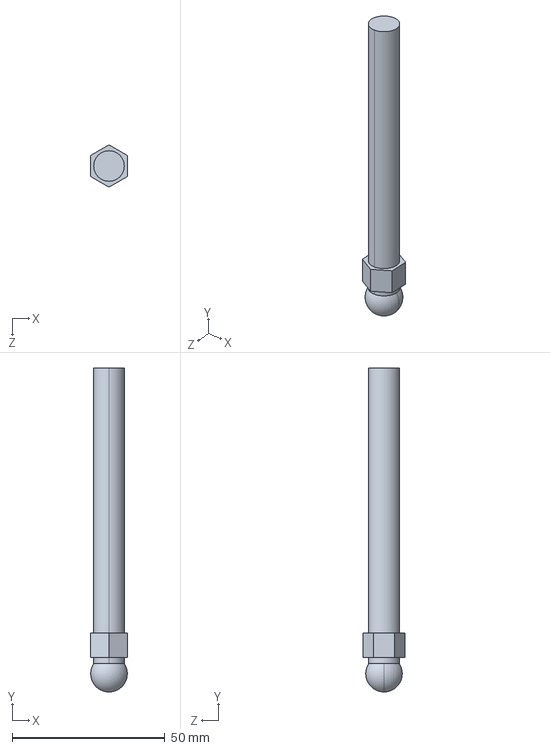
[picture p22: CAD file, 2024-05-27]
SonoRover One/hardware/Step/W0003510-56-spindle bottom feet.STEP
12.0 x 106.0 x 13.9 mm

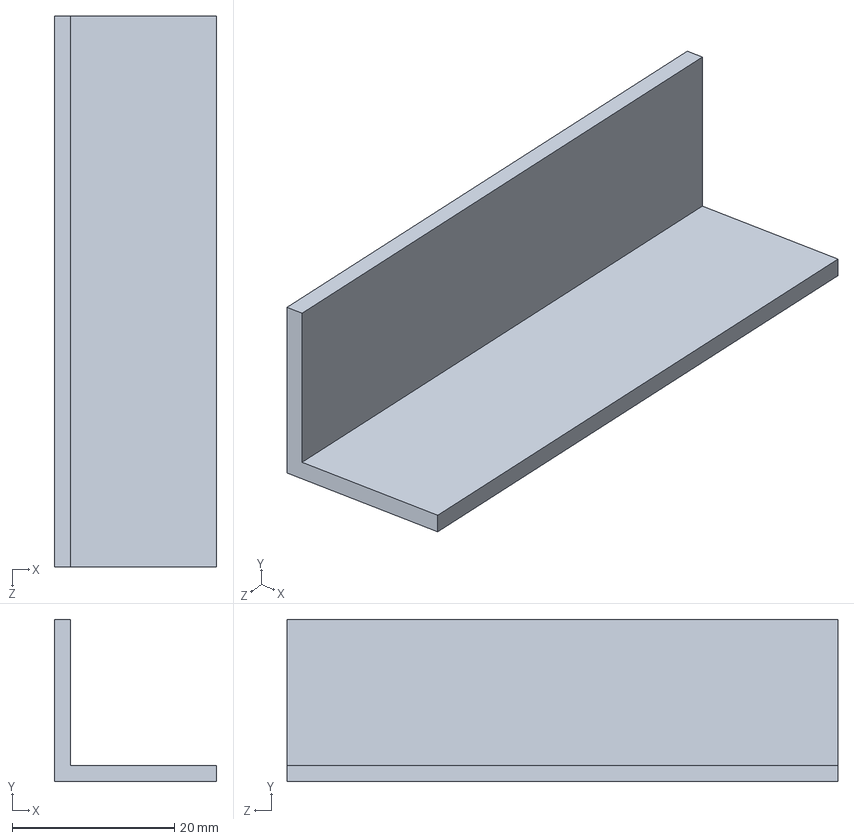
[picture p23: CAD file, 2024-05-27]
SonoRover One/hardware/Step/W0003510-73--L profile 88.STEP
20.0 x 20.0 x 68.0 mm

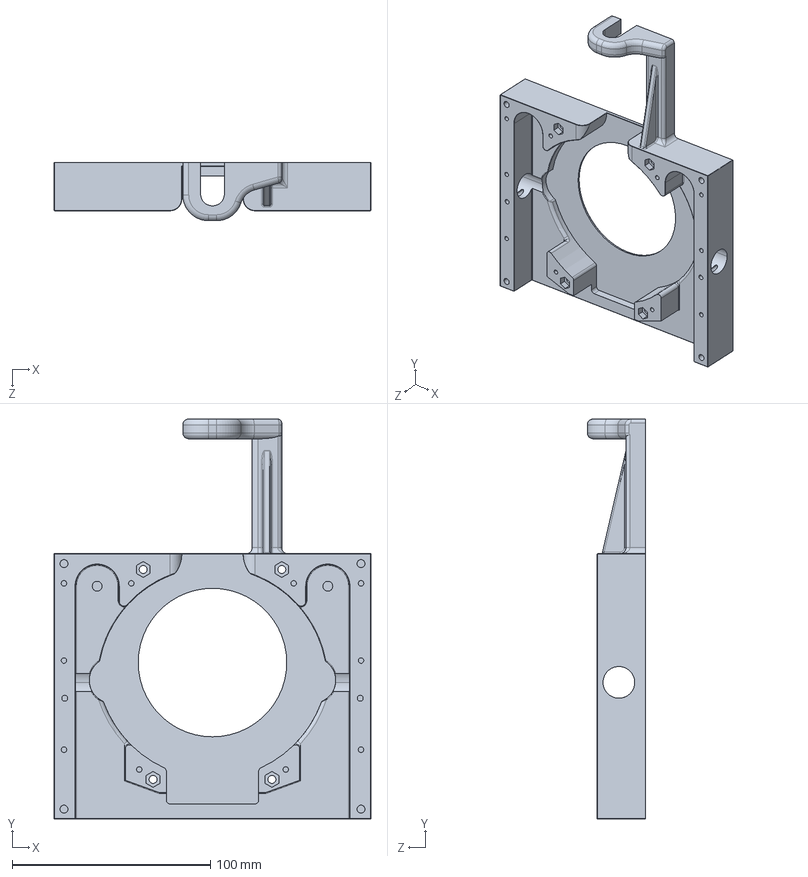
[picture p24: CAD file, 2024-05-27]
SonoRover One/hardware/Step/W0003510-001-IMASONIC-R65-81 Tranducer front plate.STEP
160.0 x 202.0 x 29.5 mm

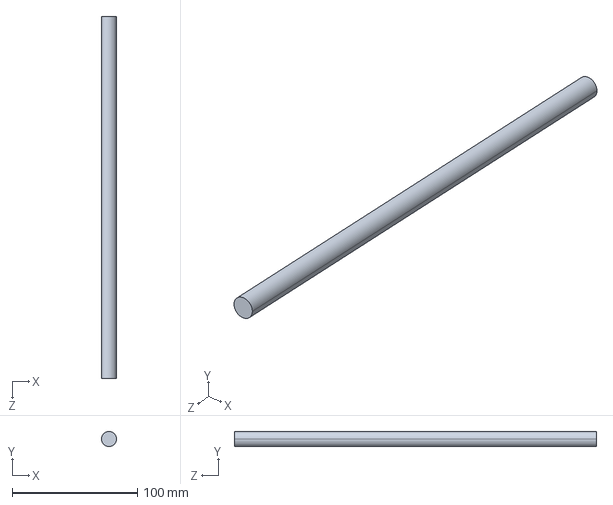
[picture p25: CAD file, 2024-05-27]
SonoRover One/hardware/Step/W0003519-13-guide setup.STEP
12.0 x 12.0 x 288.5 mm

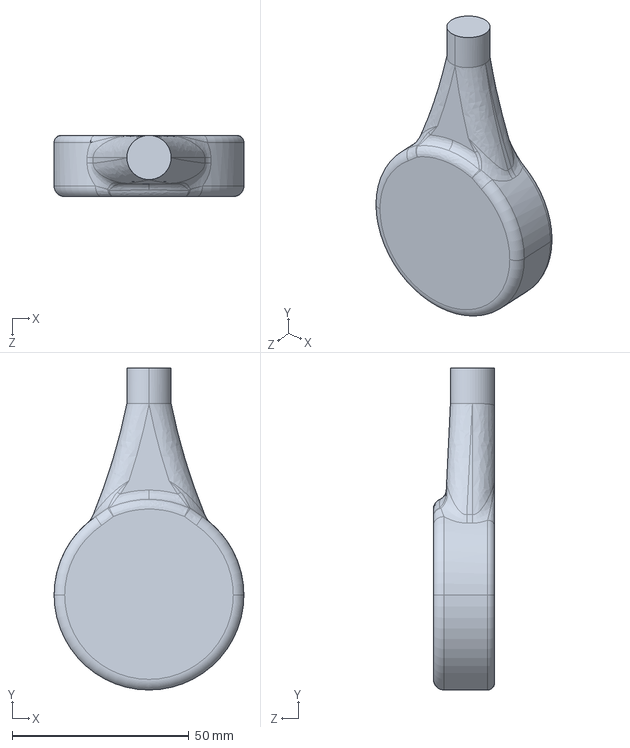
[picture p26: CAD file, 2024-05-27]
SonoRover One/hardware/Step/W0003510-012-CTX 250-09 Tranduser 53.66 mm 54.STEP
53.7 x 91.0 x 17.3 mm

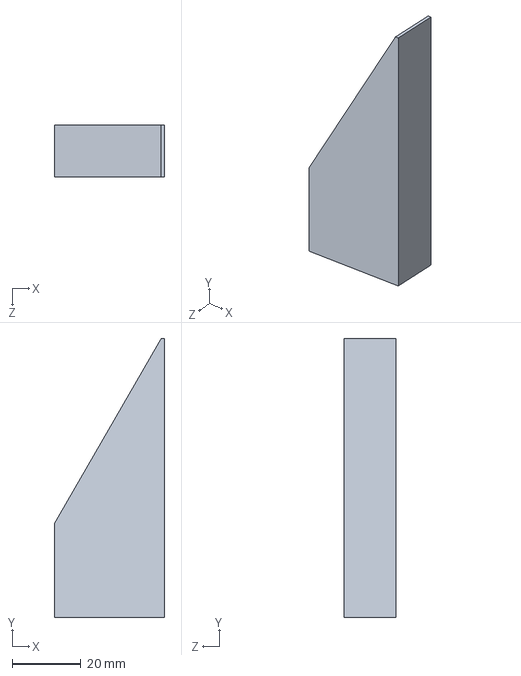
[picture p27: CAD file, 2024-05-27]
SonoRover One/hardware/Step/W0003510-79- fixation wedge.STEP
32.0 x 81.0 x 15.0 mm

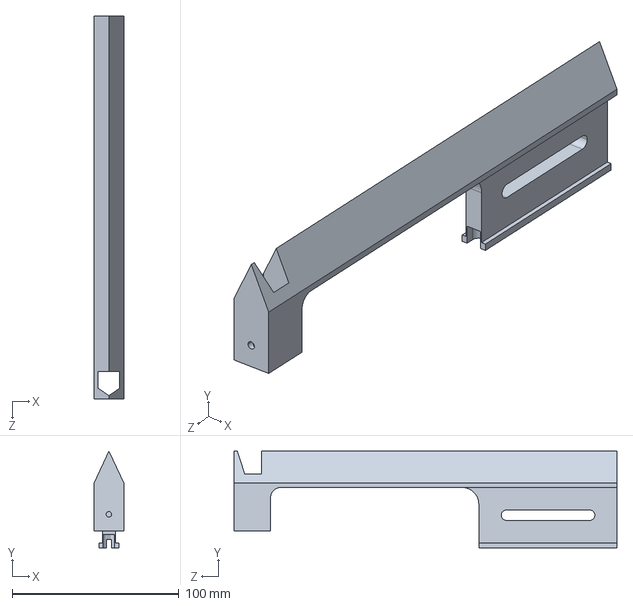
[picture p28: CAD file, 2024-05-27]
SonoRover One/hardware/Step/W0003510-21-Holder.STEP
17.9 x 58.2 x 230.0 mm

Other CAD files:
SonoRover One/hardware/Step/W0003510-00-05- spindle feet.STEP
SonoRover One/hardware/Step/W0003510-00-2- large watertank.STEP
SonoRover One/hardware/Step/W0003510-012 transducer house 72.STEP
SonoRover One/hardware/Step/W0003510-006-R-wiggle arm 81.STEP
SonoRover One/hardware/SolidWorks/W0003510-00-001-2CHG sonic concepts 54.SLDASM
SonoRover One/hardware/SolidWorks/W0003510-00-002-4CH Sonic Concepts Transducer holder 72.SLDASM
SonoRover One/hardware/SolidWorks/W0003510-00-003-Imasonic holder 81.SLDASM
SonoRover One/hardware/SolidWorks/W0003510-00-03-HGL 0200-PREAMP AG-2010.SLDASM
SonoRover One/hardware/SolidWorks/W0003510-00-04- spindle feet.SLDASM
SonoRover One/hardware/SolidWorks/W0003510-00-05- spindle feet.SLDASM
SonoRover One/hardware/SolidWorks/W0003510-00-06- spindle feet.SLDASM
SonoRover One/hardware/SolidWorks/W0003510-00-2- large watertank.SLDASM
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

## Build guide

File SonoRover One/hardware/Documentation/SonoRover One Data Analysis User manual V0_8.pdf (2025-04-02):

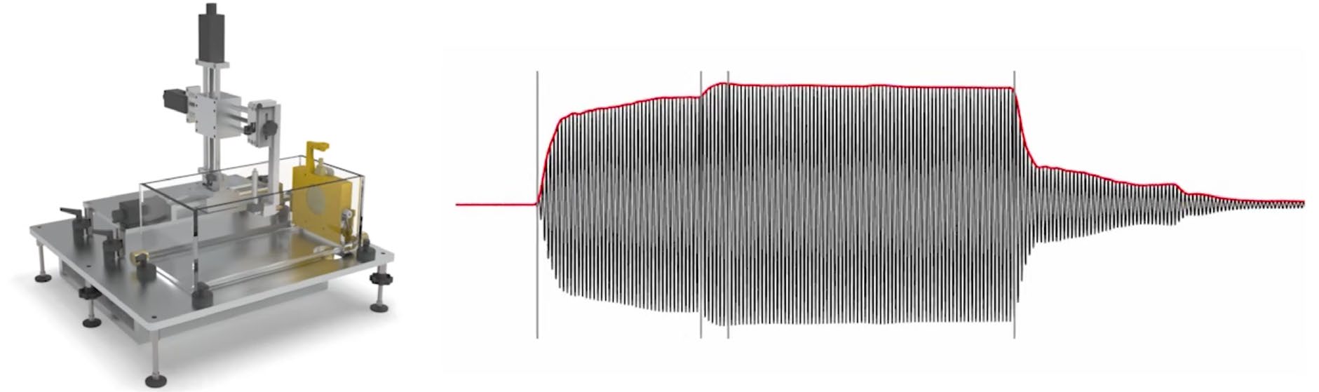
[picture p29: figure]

User manual V0.8
Wednesday, 2 April 2025

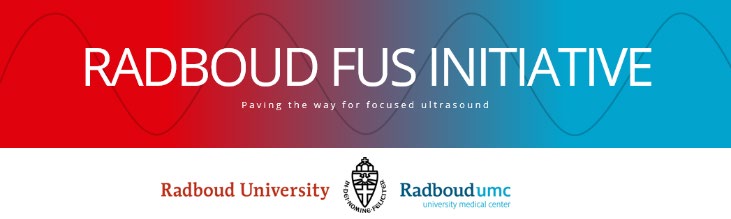
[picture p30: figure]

# User Manual

## SonoRover One Data Analysis

Document Identification and Filing
Document name | SonoRover One Data Analysis User manual V0_8
Document owner | Focused Ultrasound Initiative
Status | Under development
Version | 0.8
Location | Radboud Universiteit\FUS Initiative - Instruction manuals\SonoRover One\Data Analysis
Version control | Yes / OneDrive (no minor revision tracking - company policy)
Doc ID | SonoRover One Data Analysis User manual V0_8

Change log
Version | Date (yyyy-MM-DD) | Author(s) | Description of change(s)
0.7 | 2025-03-18 | Stein Fekkes | Document structure.
0.8 | | Stein Fekkes | First version

## Table of contents

# 1 Introduction

## 1.1 Purpose & Scope

The SonoRover One Data Analysis package is a MATLAB-based toolkit designed for advanced postprocessing of hydrophone measurements collected using the SonoRover One data acquisition system. This manual serves as a comprehensive guide for users who need to convert raw hydrophone data into scientifically meaningful acoustic parameters and visualizations.

The package is specifically tailored for applications in focused ultrasound metrology, supporting both research and clinical development environments where precision acoustic characterization is critical.

This toolkit covers the complete data processing pipeline, from raw signal preprocessing to advanced acoustic field analysis and reporting. Its main capabilities include:

- Preprocessing: Filtering and conditioning of hydrophone data (e.g., bandpass filtering, Hilbert transform).
- Pulse Analysis: Detection of pulse arrival, pulse window selection, and amplitude estimation using multiple methods (FFT, Phasor, Hilbert, and k-Wave simulations).
- Metric Calculation: Conversion of voltage signals into acoustic pressure, intensity, and ISPPA values, including scaling based on NeuroFUS calibration data.
- Spatial Filtering: Suppression of hydrophone reflection artifacts via axial Butterworth filtering.
- Acoustic Holography: Full-field sound pressure reconstruction to visualize the acoustic field in 3D space.
- Visualization and Export: Generation of plots, comparisons with reference datasets, and exporting of processed results.

The toolkit supports batch processing and is modular, allowing for future extensions to accommodate new metrics or processing techniques.

This manual provides:
- A detailed explanation of the system workflow
- Step-by-step instructions for each processing stage
- Descriptions of each module and function within the package
- Guidance on how to visualize and export results
- Recommendations for troubleshooting and best practices

## 1.2 Audience

This manual is intended for professionals and researchers who are involved in the measurement, validation, and analysis of focused ultrasound systems. Typical users include:

- Acoustic Engineers working on transducer design, beam characterization, and system optimization.
- Biomedical Researchers involved in therapeutic ultrasound, neuromodulation, and preclinical validation of ultrasound-based devices.
- Metrology and QA Specialists responsible for compliance with acoustic safety guidelines and regulatory standards.
- Lab Technicians and Operators using the SonoRover One platform for routine measurements and reporting.
- Graduate Students or academic users working on ultrasound-related projects requiring hydrophone data analysis.

A basic understanding of acoustics, hydrophone measurements, and proficiency in MATLAB is recommended to effectively use this package.

## 1.3 System Requirements

To successfully run the SonoRover One Data Analysis package, the following software and hardware prerequisites are recommended:

## 1.4 Software Requirements

- MATLAB R2024a or later
(First official MATLAB release of 2024, required for compatibility with object-oriented features and toolboxes used)
- Required MATLAB Toolboxes:
- Signal Processing Toolbox
- Image Processing Toolbox (for holography visualization)
- k-Wave Toolbox (open-source MATLAB toolbox for acoustic wave field simulations)
- natsortFiles (MATLAB utility for natural sorting of filenames)
- crossing (utility function for zero-crossing detection)

## 1.5 Hardware Recommendations

- Processor: Multi-core CPU (Intel i5/i7/AMD Ryzen 5 or higher)
- Memory: Minimum 16 GB RAM (32 GB recommended for large holography reconstructions)
- Storage: SSD drive recommended for fast data read/write (minimum 1 GB free space for datasets and outputs)
- GPU: Optional, CUDA-compatible GPU if you plan to extend functionality with GPU-accelerated MATLAB functions
Platform
- Compatible with Windows (tested on Windows 11)
- macOS and Linux may require minor adjustments for file paths and toolboxes.

## 1.6 Disclaimer

This user manual and accompanying documentation are provided for informational purposes only and pertain specifically to the in-house developed metrology system described herein. While every effort has been made to ensure accuracy, completeness, and clarity in instructions, procedures, and safety guidelines, the creators and distributors make no guarantees or warranties of any kind—expressed or implied— regarding the accuracy, reliability, or suitability of the provided information for any particular application.

Users are solely responsible for the proper setup, calibration, operation, and maintenance of the metrology system as detailed within this manual. The creators and distributors shall not be held liable for any damage, injury, or loss resulting directly or indirectly from improper installation, misuse, unauthorized modification, or deviation from the recommended procedures outlined in this manual.

The user acknowledges that the performance of the metrology system may vary based on environmental conditions, handling practices, and specific use-case scenarios. Users should undertake regular calibration and verification procedures to ensure optimal performance and reliability.

All safety instructions and best practices must be followed at all times. By operating this metrology system, the user accepts full responsibility for compliance with all applicable safety standards, regulations, and procedures.

# 2 Installation

## 2.1 Download and add package to MATLAB path

Go to GitHub repository page: https://github.com/Donders-Institute/Radboud-FUS-measurement-kit/tree/release/SonoRover%20One%20Data%20Analysis (https://github.com/Donders-Institute/Radboud-FUS-measurement-kit/tree/release/SonoRover%20One%20Data%20Analysis) Click “code” > Download ZIP and extract to an desired working directory.

## 2.2 Folder structure overview and dependencies

- SonoRover-One-Data-Analysis/
- ├── classes/ | # Object-oriented classes for data processing
- │ ├── dataPrep.m
- │ ├── dataCalc.m
- │ ├── dataVis.m
- │ ├── dataExp.m
- │ └── readNF.m
- ├── externalData/ # Contains calibration data and supporting NeuroFUS files
- │ ├── HydrophoneType# Hydrophone calibration data
- │ └── NFD.mat | # Reference data of NeuroFus portfolio
- ├── functions/ | # Utility functions
- │ ├── cwater.m
- │ └── readIniFile.m
- ├── SonoRover One | # output example files
- ├── Toolboxes/ | # Third-party toolboxes
- │ ├── crossing.m | # downloaded form MATLAB central
- │ ├── natsortfiles.m | # downloaded form MATLAB central
- │ └── k-Wave | # downloaded from https://www.k-wave.org/
- └── index.m | # Main script file (entry point)

## 2.3 First-Time Setup

- Add the correct hydrophone txt calibration data in externalData folder. The data is read at the initialisation of an dataCalc.m object.

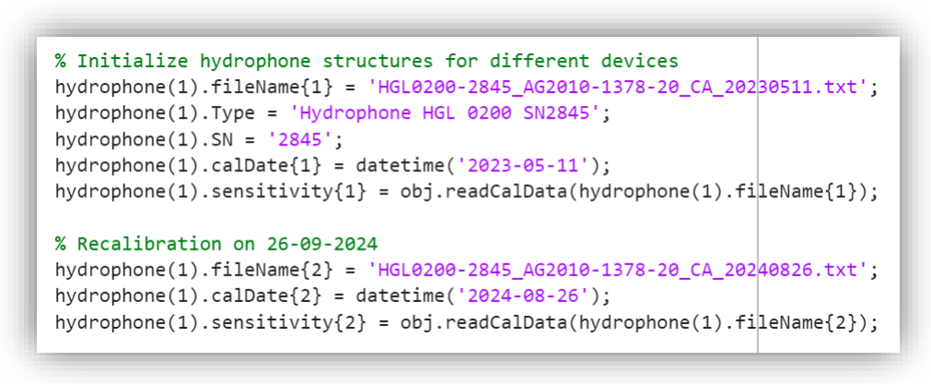
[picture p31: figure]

- Building the NeuroFus data mat file using the provided .xls reference data sheets by Sonic Concepts by defining and correctly referencing using the readNF.m class/

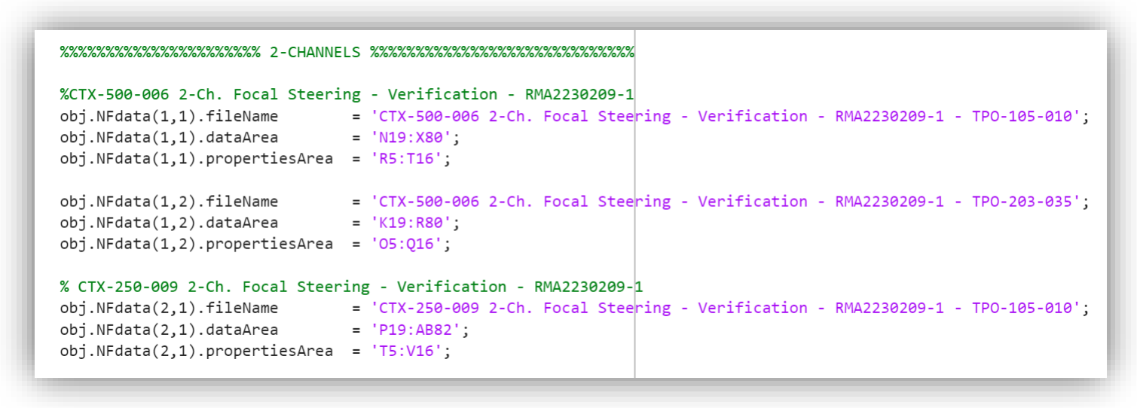
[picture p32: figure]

- Open index.m which is the main file and define parameters in the following sections;
- Initialize environment make sure you set the correct paths
- pr.defaultDataPath
- pr.defaultDataPathTesting -> omits the input dialog box and the browsing actions
- pr. neuroFUSFolderLocation -> location of the .xls reference sheets
- Define input parameters
- pr.rereadNFD = true -> make sure to build the MATLAB data file in case it does not exist or needs updating after adding a new reference file

# 3 Workflow Overview

## 3.1 SonoRover One acquisition files

Data is collected using the SonoRover One system which is described in a separate user manual which contains the following actions

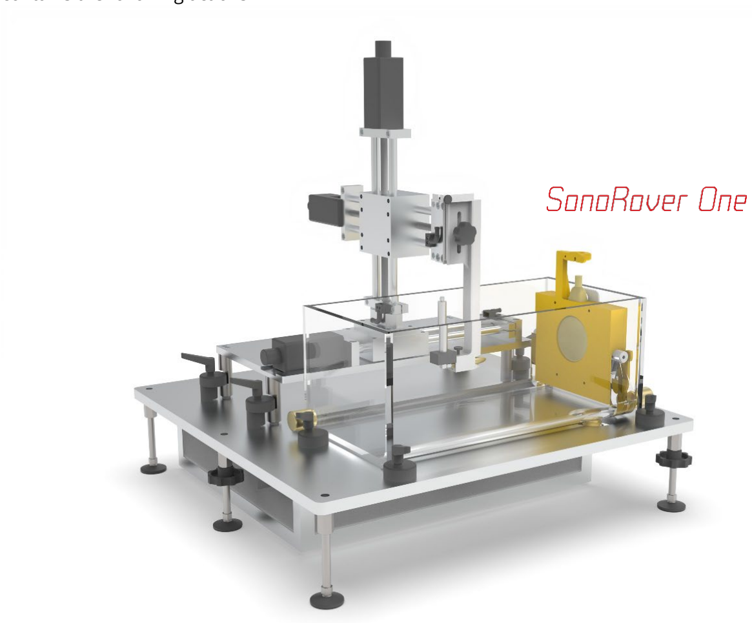
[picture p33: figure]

Figure 1. The SonoRover One metrology setup

- Mechanical Probing and Stage-Alignment
- Water Preparation
- Transducer Mounting
- Transducer Connection
- Hydrophone Mounting.
- Acoustical axis estimation
- Define & execute measurement sequences

Output example files are provided in the SonoRover One folder for each sequence consist of
- | *data.acd | # Legacy file, not used
- | *data.ini | # text file with SonoRover One acquisition properties
| • Versions
- Equipment
- Sequence
| • Grid

- Acquisition
- ACD processing
- | *data.raw | # Raw data
- | *data.csv | # Absolute and relative measurement position coordinates

## 3.2 Post-processing steps:

1. Data import & preprocessing
2. Pulse selection and windowing
3. Amplitude estimation
4. Spatial filtering & reflection mitigation
5. Calculation of acoustic metrics (Pressure, ISPPA)
6. Holography reconstruction if applicable
7. Visualization & Export

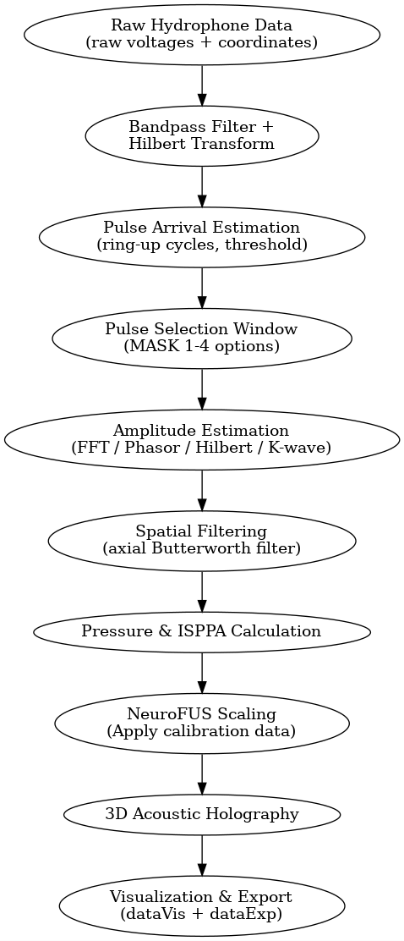
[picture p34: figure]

# 4 Step-by-Step Guide

## 4.1 Initialization

Read and prepare SonoRover One data by creating an object prepData.

- Class dataPrep.m [prepData, setNrs] = dataPrep(pr,pl);

Handles the import and preprocessing of raw hydrophone data. Steps include:
- Reading raw data and coordinates
- Applying bandpass filtering
- Envelope detection (Hilbert transform)
- Estimating pulse arrival and window selection
1. When the devMode parameter is false, a dialog box appear, navigate to the folder which contains output files by the SonoRover One (See paragraph 3.1). This will read all sequence files.

When files need to be appended select “Yes”. This will read the additional sequence files alongside the first import. If finished continue by pressing “No”

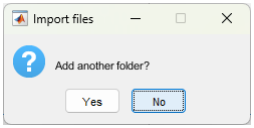
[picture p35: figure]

2. A finite impulse response (FIR) filter with a fixed bandwidth of 100 kHz around the center frequency and a relatively high filter order of 100 was applied. By using the filtfilt function, zero-phase filtering was achieved, which is essential for accurately estimating the arrival time and determining the distance from the hydrophone to the exit plane.
3. The envelope was calculated using the Hilbert transform and normalized for pulse index estimation and optional ring-up characteristics and additional analyses.
4. Estimate the arrival of the pulse at the hydrophone and corresponding selection window using the estimated pulse index based on thresholding and based on axial hydrophone location w.r.t. the transducer.
5. prepData.pulseIndexEst(setNrs,1,ringUpcycles,selectionCycles,time,threshold ,EPoffset);
a. setNrs: | the sequence number selection
b. ringUpcycles: | number of periods to exclude from the onset of the pulse, (skipping
| ring up phase)
c. selectionCycles: the number of periods to take into account for amplitude estimation
d. time: | a certain timeperiod [microseconds] from the start of pulse
e. threshold: | [%] of normaliseer amplitude

f. EPoffset | the length between the center of the membrane and the exit plane (specific for each transducer type)

Figure 2 show the estimation of the pulse arrival sample versus the axial distance w.r.t. the transducers radiating surface using the thresholding method in blue and the linear propagating soundwave characteristics in red.

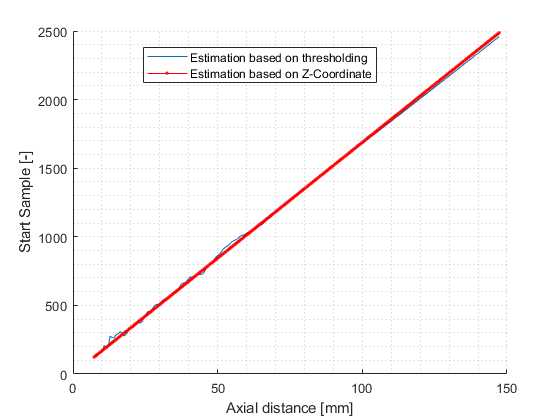
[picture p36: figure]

Figure 2. Onset of pulse detection versus Axial distance

6. Estimate the pulse selection window used as the signal input for amplitude estimation.

prepData.pulseWindow(setNrs,mask);

a. setNrs: | the sequence number selection
b. mask | 1: in between end of ring up period and end of pulse
| 2: in between 3TOF minus selection Cycles and 3TOF
| 3: in between end of ring up period and end of ring up period + selection
| cycles
| 4: at a certain time selection – selection Cycles to certain time.

For each mask type the selection window will be visualized in the figure 3a-d using 25 ringup cycles, 5 selection cycles, 80 microseconds time, threshold of 10% and a offset of 7.3 mm.

a) Mask 1 : in between end of ring up period and end of pulse

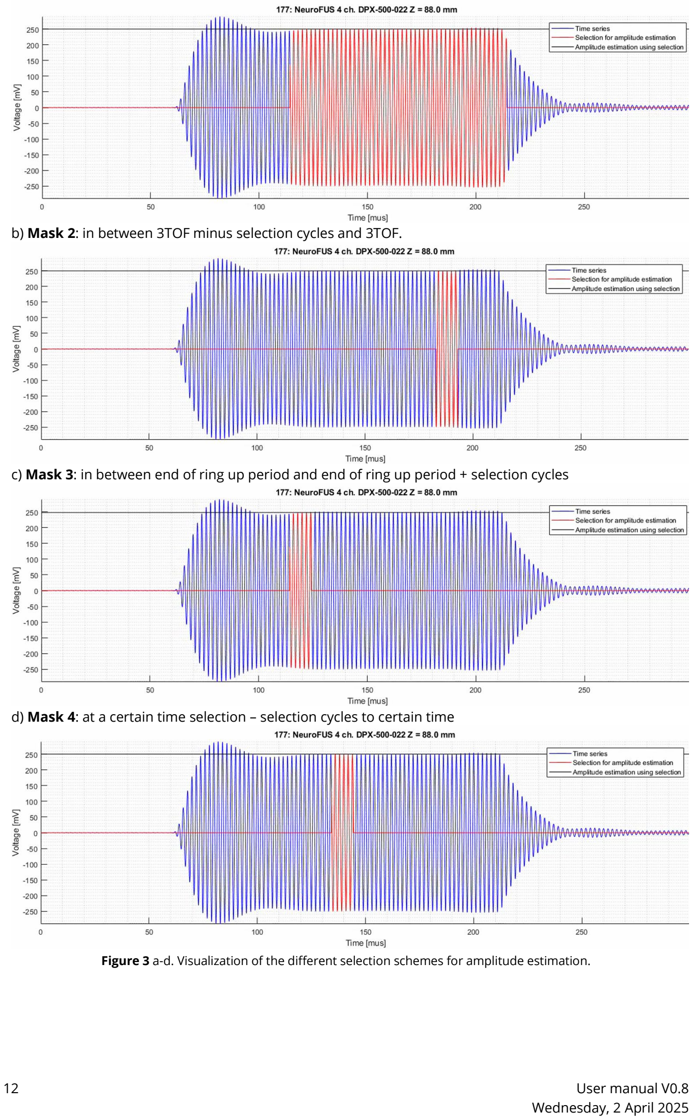
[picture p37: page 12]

b) Mask 2: in between 3TOF minus selection cycles and 3TOF.
c) Mask 3: in between end of ring up period and end of ring up period + selection cycles
d) Mask 4: at a certain time selection – selection cycles to certain time

Figure 3 a-d. Visualization of the different selection schemes for amplitude estimation.

## 4.2 Data processing

- Class dataCalc.m calcData = dataCalc(prepData);

Core calculation engine which performs:
- Amplitude estimation (FFT, Phasor, Hilbert, K-wave)
- Spatial filtering (Butterworth)
- Pressure and intensity calculations
- ISPPA computation and scaling with NeuroFUS data
- Acoustic holography (3D sound field reconstruction)
1. Creates the object with the prepData as input data object. In the constructor of the file hydrophone calibration data is set accordingly:

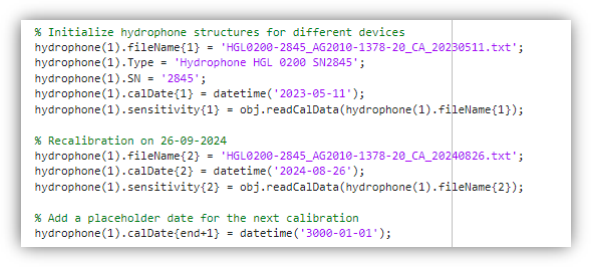
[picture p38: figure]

2. Estimation of the amplitude using the selected data window

calcData = calcData.calcAmplitude(ampEstMethod);

a. ampEstMethod 1. FFT based
2: Phasor based
3: Hilbert transform
4: using K-Wave toolbox
3. In case of an axial acquired profile in which only movement along the z axes occurs spatial filtering is applied to mitigate the possible reflection interference from the hydrophone itself which happens at the 3 TOF

calcData = calcData.calcSpatialFiltering(scf,ripple,passBandAtten);

a. scf | spatial cutoff frequecy [1/mm]
b. ripple | passband ripple [dB]
c. passbandAtten stopband attentuation in [dB]
4. The next steps convert the raw hydrophone electrical signal from Volts to pressure

calcData = calcData.calcPressure();

For this, hydrophone calibration data defined in the constructor of the class upon object creation in step 1 was used. In case of multiple calibration dates of a single hydrophone, figure depicts both sensitivity curves.

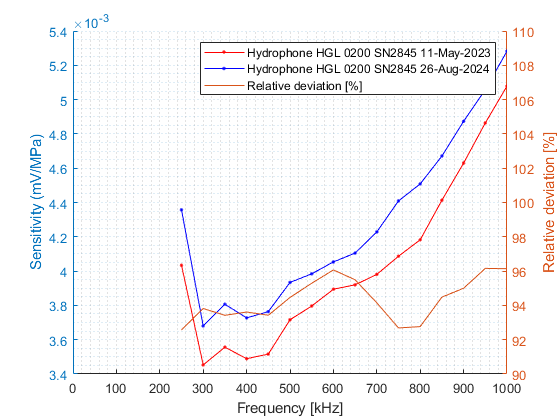
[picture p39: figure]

Figure 4. Hydrophone sensitivity curves of multiple calibration dates

5. Consequently, the intensity and ISPPA are calculate using the following functions

calcData = calcData.calcIntensity();
calcData = calcData.calcISPPA();
6. In case of the comparison with reference data provided by Sonic Concept of the NeuroFus transducers, the NFD structure constructed in the import and prepare data section (paragraph 2.3) was used to scale the calculated ISPPA profiles using the ratio of the max power per channel setpoints of the NeuroFus and SonoRover One profiles.

calcData = calcData.calcISPPA2NFscale(NFD);

7. In case a cross-sectional plane in front of the transducer was measure. Holography using the K-Wave toolbox functionality can be performed.

calcData = calcData.calcHolography(ipf,zv);

a. ipf | [#] Interpolation factor of amplitude and phase data
b. zv | [m] The axial vector used for reconstruction of the 3D volume data

## 4.3 Visualisation

- Class dataVis.m dataVisual = dataVis(prepData,calcData);

Visualization toolbox. Generates:
- Pulse selection plots
- Axial profile comparisons with NeuroFUS data
- 3D holography visualizations

Upon creation of the object, a folder “postprocessing” has been created in which all the visualization from all methods are stored

1. To visualized the filtered pulse selection recording for each sequence the following method can be used. This will generate a video of all pulses within a sequence for all sequences. A snapshot of a possible pulse visualisation is depicted in figure 3a-d.

dataVisual.pulseSelection(setNrs,xAxis{2},yAxis{1});

a. X axis | 1: Samples [#]
| 2: Time [µs]
| 3: Cycles [#]
b. Y axis | 1:Voltage [mV]
| 2: Pressure [MPa]
- To visualize the axial profiles for all sequences in a single graph or in a container in which you can scroll trough the single profiles the following method can be used.

dataVisual.axialProfiles(setNrs,xAxis{1},yAxis{y},NFD,singleView{sv});

a. setNrs | For selected sequences
b. X axis | 1: Distance WRT exit plane [mm]
c. Y axis | 1: Voltage [mV]
| 2: Raw & Filt pressure [MPa]
| 3: Pressure [MPa]
| 4: ISPPA [W/cm²]
| 5: ISPPA scaled [W/cm²]
d. singleView | 1: true: all-in one figure like displayed in figure 5
| 2.false: embedded in a container to scroll through the profiles

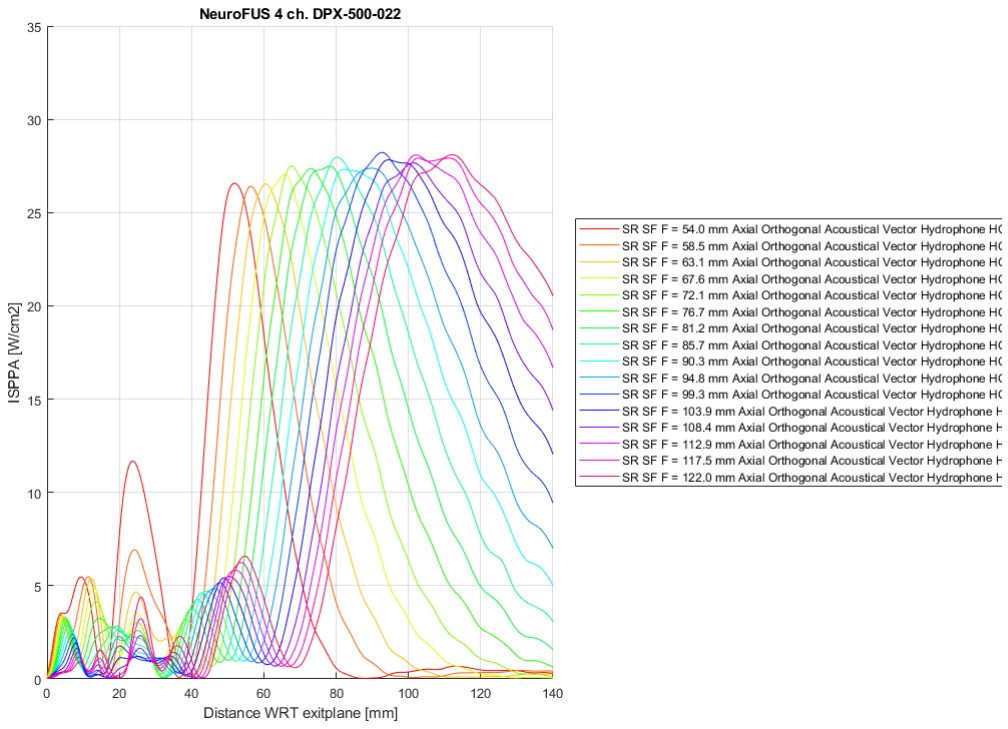
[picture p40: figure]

Figure 5. Visualization of ISPPA profiles for specific focus setting

- To visualize the results obtained uing the holography method, the following visualization method can be used

dataVisual.holography(transverseLoc,zv)

a. transverseLoc | Axial location vector in [mm] of cross-sectional views
b. zv | Axial vector for cross-sectional holography calculations, see
| paragraph 4.2.7
1. A Native versus Holography derived central axis profiles are plotted to compare the actual measured axial profile with the reconstructed one based on the holography calculation.

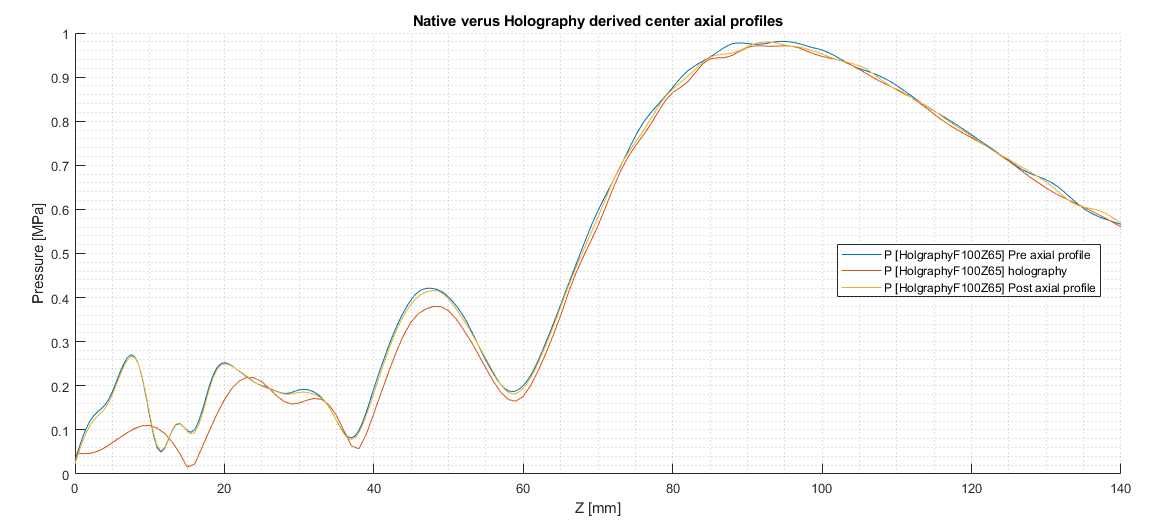
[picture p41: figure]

Figure 6. Visualization of the axial profiles

2. The raw amplitude and phase obtained at the single cross-section used as input for the holography method. The input plane has been cropped to maintain the circle symmetry nature of the pressure field. Finally an FFT based interpolation in the horizontal and vertical direction are performed before feeding into the holography algorithm.

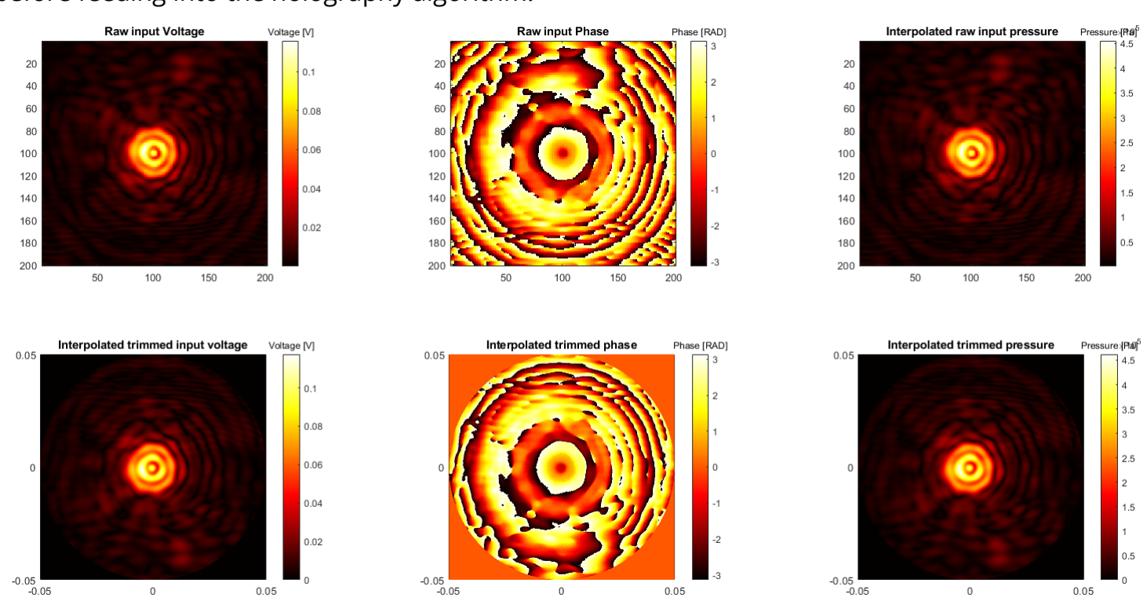
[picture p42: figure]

Figure 7. Visualization of the cross-sectional views of the input amplitude and phase and its masking and interpolation.

3. Cross-sectional views defined by transverseLoc are displayed

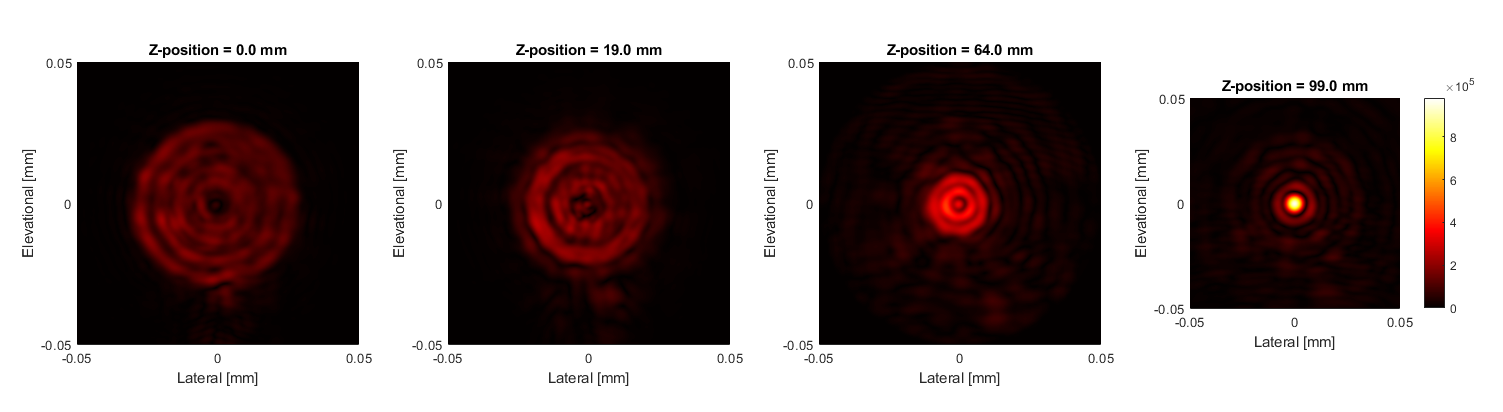
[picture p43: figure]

Figure 8. Visualization of the pressure at different axial cross-sections as a result of the angular spectrum algorithm.

4. Lateral, elevational and Transversal cross-sections of the 3D pressure field are viewed

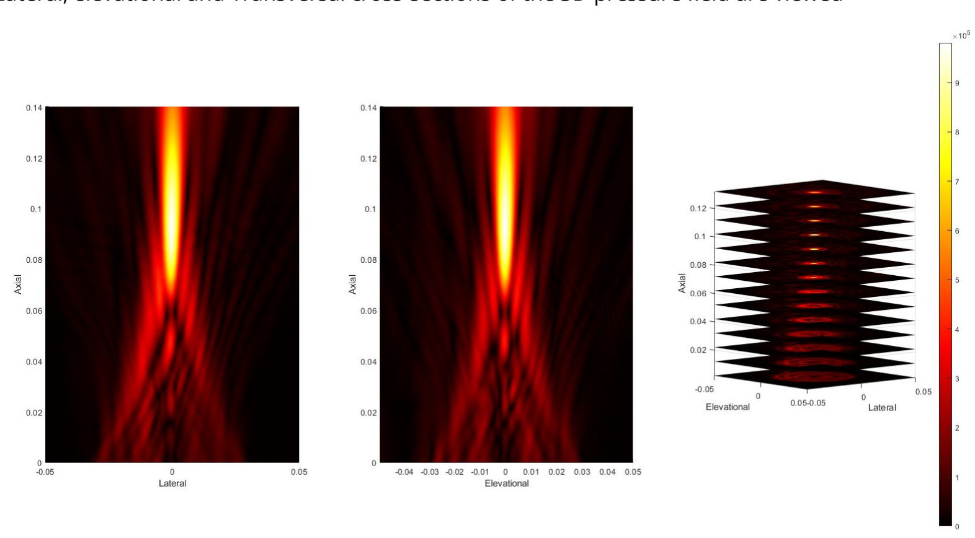
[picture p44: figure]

Figure 9. Visualization of the lateral and elevational planes supplemented with a sliced 3D view of the pressure.

## 4.4 Data Export

- Class dataExp.m expData = dataExp(prepData,calcData);

Upon creating the dataExp object, a designated folder named Export will be created in the location of the input files.

1. The export of the pressure and the ISPPA data alongside measurement properties stored in a struct as depicted below.

expData.press_ISPPA(fileName)

a. fileName | Custom filename of the export structure

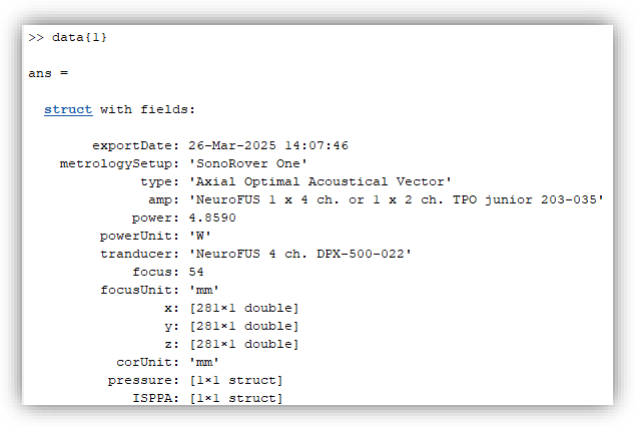
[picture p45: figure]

User manual V

0.8

# 5 Changelog

## 5.1 Version history

March 2025 | Initial version

# 6 Contact / Support

For direct contact: fus@ru.nl

## 6.1 Links to repository or project page (e.g., GitHub)

Code resources https://github.com/Donders-Institute/Radboud-FUS-measurement- kit/tree/release/SonoRover%20One%20Data%20Analysis (https://github.com/Donders-Institute/Radboud-FUS-measurement-kit/tree/release/SonoRover%20One%20Data%20Analysis)

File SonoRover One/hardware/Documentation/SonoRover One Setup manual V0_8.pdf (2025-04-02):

# Setup manual

## SonoRover One metrology platform

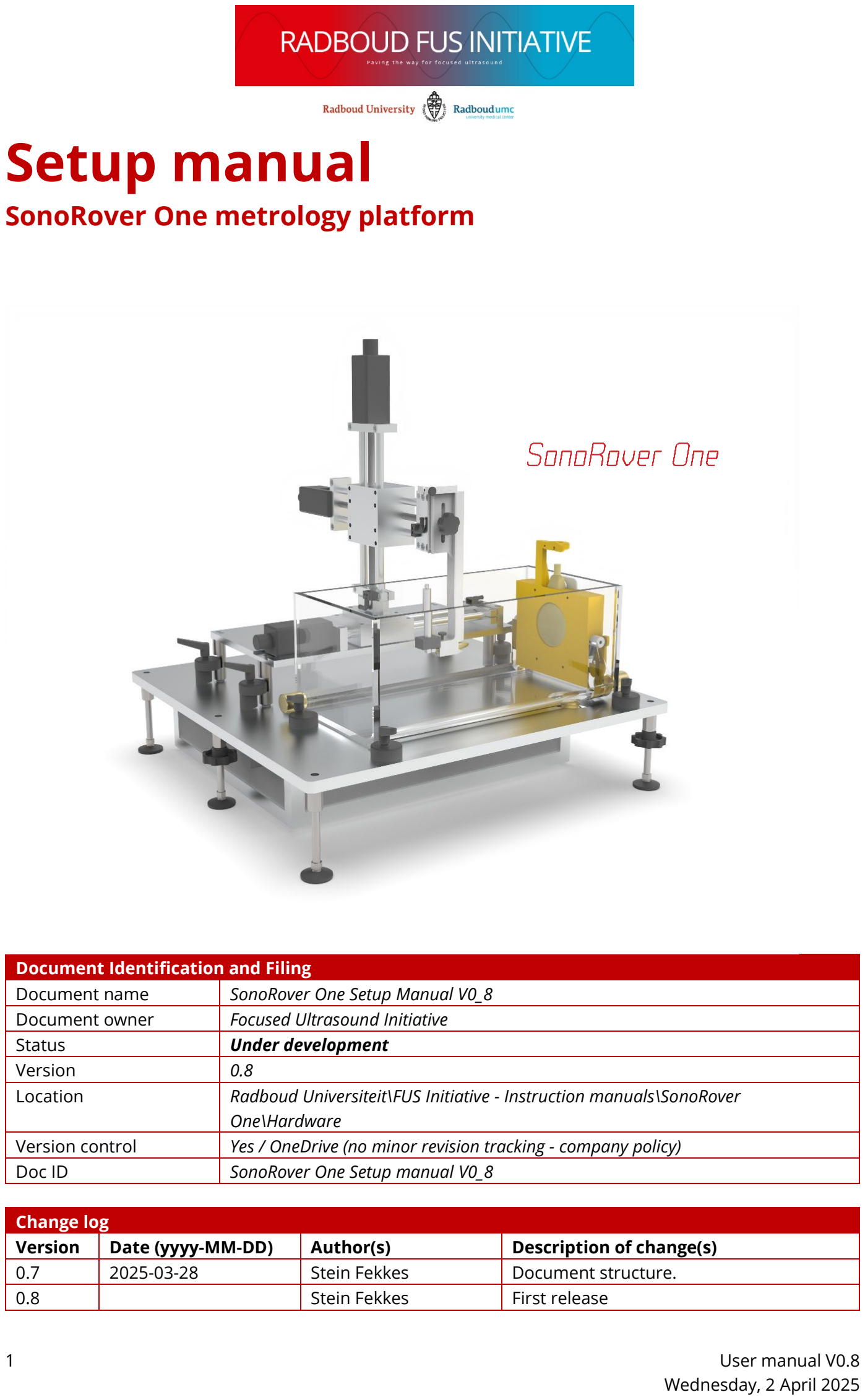
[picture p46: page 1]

User manual V0.8
Wednesday, 2 April 2025

Document Identification and Filing
Document name | SonoRover One Setup Manual V0_8
Document owner | Focused Ultrasound Initiative
Status | Under development
Version | 0.8
Location | Radboud Universiteit\FUS Initiative - Instruction manuals\SonoRover One\Hardware
Version control | Yes / OneDrive (no minor revision tracking - company policy)
Doc ID | SonoRover One Setup manual V0_8

Change log
Version | Date (yyyy-MM-DD) | Author(s) | Description of change(s)
0.7 | 2025-03-28 | Stein Fekkes | Document structure.
0.8 | | Stein Fekkes | First release

## Table of contents

# 1 Introduction

## 1.1 Purpose & Scope

The SonoRover One Metrology Platform is an open-source hardware toolkit specifically designed for precise and efficient hydrophone measurements of low-intensity focused ultrasound (LIFU) systems. Its primary purpose is to provide researchers, developers, and clinicians with an accessible, reliable, and standardized method for characterizing acoustic performance across diverse ultrasound transducer portfolios.

The platform facilitates accurate acoustic metrology, enabling users to rapidly assess transducer characteristics such as acoustic intensity distribution, focal spot accuracy, and output consistency. By leveraging open-source acquisition systems, SonoRover One promotes transparency, reproducibility, and collaborative development within the focused ultrasound community.
The scope of this platform encompasses both research-oriented and clinical development environments, addressing the critical need for precision in acoustic measurement to ensure safety, efficacy, and standardization in therapeutic ultrasound applications.

This manual provides comprehensive guidance, including:
- Detailed explanations of the hardware system components and architecture
- Step-by-step instructions for initial setup and calibration
- Best practices for measurement accuracy and reproducibility

Through open collaboration, the SonoRover One Metrology Platform aims to foster innovation and accelerate advancements in focused ultrasound technologies by providing robust, standardized tools for acoustic characterization.

## 1.2 Audience

This manual is intended for professionals and researchers who are involved in the measurement, validation, and analysis of focused ultrasound systems. Typical users include:
- Acoustic Engineers working on transducer design, beam characterization, and system optimization.
- Biomedical Researchers involved in therapeutic ultrasound, neuromodulation, and preclinical validation of ultrasound-based devices.
- Metrology and QA Specialists responsible for compliance with acoustic safety guidelines and regulatory standards.
- Lab Technicians and Operators using the SonoRover One platform for routine measurements and reporting.
- Graduate Students or academic users working on ultrasound-related projects requiring hydrophone data analysis.

## 1.3 Environmental Requirements

To successfully setup and use the SonoRover One Metrology Platform, mechanical stability, Water condition, room conditions and safety and ergonomics should be taken into account. Make sure the supporting table is sturdy. The water remains stable at ambient temperature during the measurements in a climate controlled room with nominal humidity. No additional mechanical vibrations other than generated by the XYZ-stage.

## 1.4 Disclaimer

This user manual and associated documentation for the data analysis software tool provided herein are intended exclusively for guidance and informational purposes. Although every reasonable effort has been taken to ensure accuracy, correctness, and completeness, no guarantees or warranties—expressed or implied—are made regarding the software's functionality, reliability, suitability, or fitness for any particular purpose.

Users are solely responsible for verifying the accuracy and appropriateness of the software outputs and analyses, as well as the software's suitability for their specific data analysis tasks. The creators and distributors of the software disclaim all liability for any inaccuracies, errors, or consequences arising from the use, misuse, or interpretation of software results.

The user acknowledges that software performance may be influenced by factors including but not limited to system hardware configurations, operating environments, data integrity, and user input accuracy. Regular validation and verification procedures must be conducted by the user to ensure accurate and dependable results.

By using this software tool, the user agrees to assume full responsibility for compliance with applicable data protection, privacy regulations, and industry standards

# 2 Parts list

Refer to the CAD parts list stored at GIT (https://github.com/Donders-Institute/Radboud-FUS-measurement-kit/tree/release/SonoRover%20One/hardware) for a complete and detailed parts description. The list below is overview of the high level assemblies which might consist of subassemblies

- XYZ stage
Qty | Component | Description
1 | 3-Axis CNC frame* | CNC-style frame with linear rails and lead screws for hydrophone movement
| 3 NEMA 17 Stepper Motors
3 | End stops and limit switches * | Used for safety range and homing procedure
1 | Stage base plate | Stage base plate with 4 dowel pins for correct and reproducible alignment on parent base plate
1 | Hydrophone bracket screw and washer* | To fixate the hydrophone bracket to the XYZ stage in a reproducible manner making use of a reference plate
1 | Power adaptor | 24V
- Hydrophone
Qty | Component | Description
1 | Hydrophone bracket | 3D SLA printed bracket minimizing direct acoustic reflections*
1 | HGL Preamplifier | The HGL series of Onda are complemented with a cylindrical 90 degrees preamp AG-2010
1 | HGL hydrophone | HGL 0200
1 | Preamplifier offset block | Plastic block with a tight fitting around the preamp for correct and reproducible offset
1 | BNC to preamplifier coax-cable | ~60 cm long galvanic connection to DC power and oscilloscope connection
1 | Power adaptor | 24V 0.625A
- Probe holders
Qty | Component | Description
1 | 2-channel base holder | Grey holder which hosts all 2-channel NeuroFus transducers
1 | 4-channel base holder | Yellow holder which hosts all 4-challen NeuroFus transducers
1 | Imasonic R100 and R75 base holder | Red holder which host R100 and R75 10 elements transducers
1 | Back plate | The white back plate to push the transducer towards the front plate of the holder
1 | 2-channel probing cylinder | The centred hollow cylinder for probing exit plane
1 | 4-channel probing cylinder | The centred hollow cylinder for probing exit plane
1 | Imasonic probing cylinder | The centred hollow cylinder for probing exit plane
1 | Probing dummy hydrophone | The stainless steel dummy hydrophone

1 | 2-channel offset disk | Plastic offset disk for transducer fixation using the back plate
1 | 4-channel offset disk | Plastic offset disk for transducer fixation using the back plate
1 | Imasonic offset disk | Plastic offset disk for transducer fixation using the back plate
- Water tank
Qty | Component | Description
1 | Acrylic water tank | 400x200x200 mm (LxWxH)
1 | AptFlex F28 sheet | ~200x200 mm High-frequency acoustic absorber designed to minimize unwanted ultrasonic reflections and provide effective acoustic isolation
2 | In and output sockets | Brass quick connector for water hoses
- Base plate
Qty | Component | Description
1 | Base plate | Aluminium baseplate 600x600 mm
3 | Set feeds screws | Used to level the base plate
2 | Lock feeds screws | If level, make sure this setting is kept
4 | XYZ Fixation locks | XYZ stage lockers
1 | Reference rig | The reference for positioning the water tank
3 | Water tank fixation disk locks | Locking the water tank towards the reference rig and secure its position
4 | Shock absorbers | Vibration absorber plates underneath the base plate feet’s
- Cabinet
Qty | Component | Description
1 | Cabinet | Box to contain all electronics and hovering above the floor
1 | Oscilloscope | 4 channel PicoScope with external power supply
1 | Power strip
1 | Plug used for grounding | PicoScope grounds to net-ground
1 | USB 3 hub | External powered USB 3 hub
1 | 50 Ohm BNC RF terminator | Impedance matching between the hydrophone and the oscilloscope
- Pump and degasser
Qty | Component | Description
1 | pump | Degasser pump by IGT
1 | Power adaptor | 24V
2 | Silicon hoses | 1.5 meters of silicon hoses with quick -lock connectors in between pump and water tank
- Peripherals
Qty | Component | Description

1 | Dissolved oxygen and temperature measurement device | Hanna HI98198 portable dissolved oxygen measurement device
1 | De-ionized water filter system | https://demiwatermaken.nl/product/saleskit/
2 | Plastic containers 10L | For de-ionized water and waste water
- Computer
Qty | Component | Description
1 | Desktop computer | Current desktop computer with fast USB-C data throughput
2 | Desktop screens
1 | Keyboard
1 | Mouse

*Original by IGT and modified by Radboud University

# 3 Installation

## 3.1 Initial setup instructions

1. Initial placement
Place the container box, pump and optional anti-vibration pads at a stable table 1) Oscilloscope 2) Powered USB 3 hub 3) Power socket 4) Pump/degasser 5) Anti-Vibration pads | 3 4 2 1 5

2.
Position the base plate over the container box on top of the anti-vibration pads 1) Base plate 2) Reference rig 3) Hydrophone pre-amplifier | 1 2 3

3.
Level the plate using the leveller on top by adjusting the screws at position 1,2,3... the anti-vibration pads will absorb minor changes 1) Lever screw 2) Locking screw 3) Leveller | 2 1 3

4.
fixate the container below the base plate. Raise the whole container such that the sides are flush with the holders and push it towards the back. Secure it by rotation the front disk 1) Sliders 2) Locking disk | 1

5

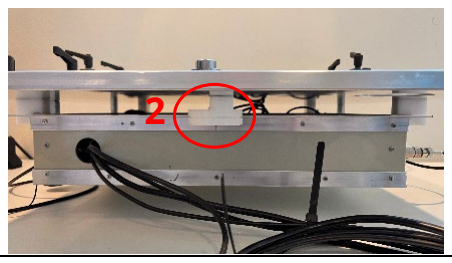
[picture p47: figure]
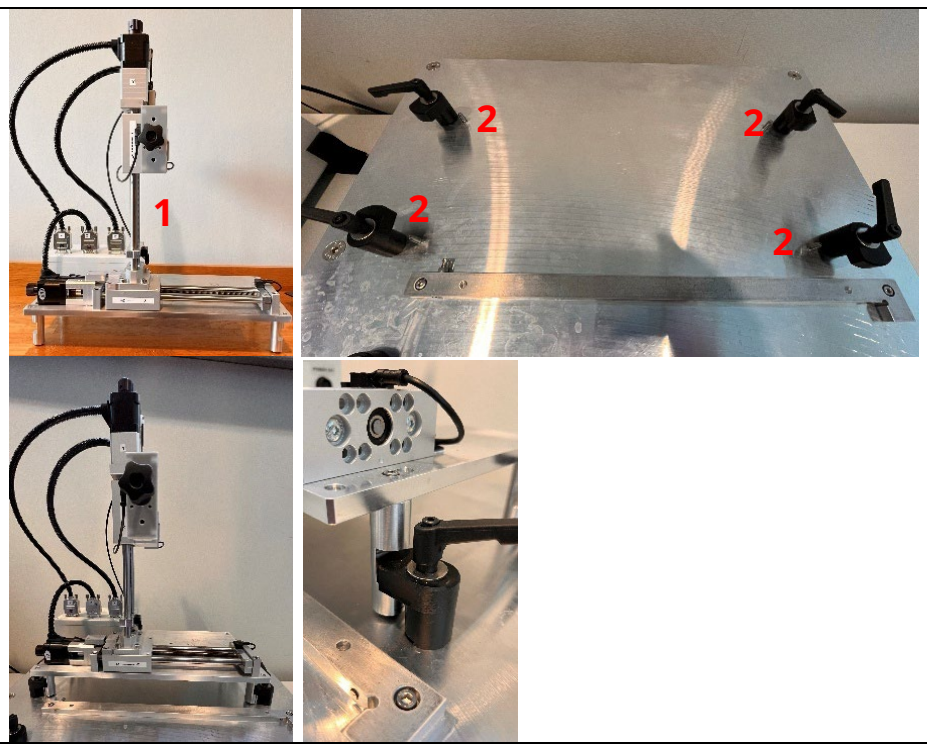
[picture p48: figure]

Place the stage assembly at the baseplate over the cylinders and secure them with the fasteners 1) XYZ-stage 2) Stage lockers | 2 2 1 2 2

6

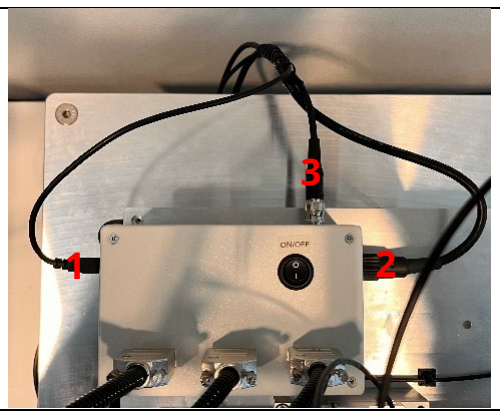
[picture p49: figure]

Connect the stage cables 1) Power 2) Data 3) BNC (probing) | 3 1 2

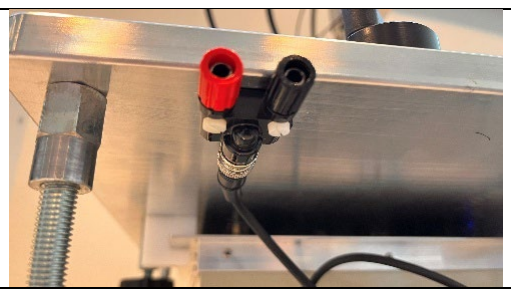
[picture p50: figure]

7
connect the BCN for mechanical alignment (probing) (the colours suggests polarity but this is not the case)

8

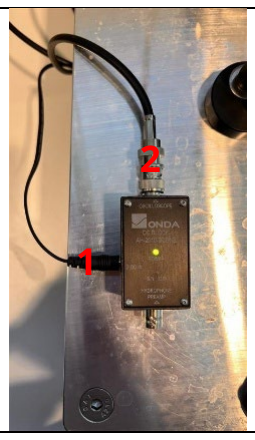
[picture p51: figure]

If applicable: connect the hydrophone preamplifier 1) Power 2) BNC to 50 ohm load prior to oscilloscope | 2 1

9

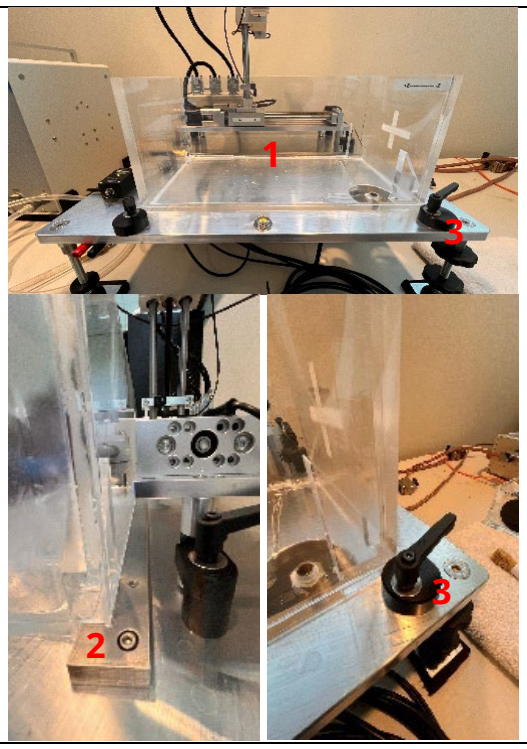
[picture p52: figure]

Place the water tank, and make sure its flush with the reference on the right upper corner. Then rotate the disks and fixate them with the bracket on top. To this for the upper left, lower left and lower right disks. This will secure the water tank in place and secure orthogonality w.r.t. the XYZ-stage orientation. 1) Water tank 2) Reference 3) Locking disks | 1 3 3 2

10

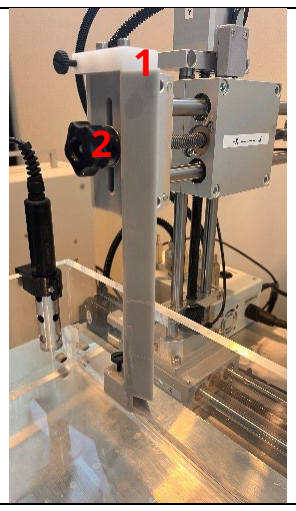
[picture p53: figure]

Mount the hydrophone connection bracket and fixate while pushing toward the left and downward against the references, then tighten the screw. 1) Reference 2) Locking screw | 1 2

11

4

4

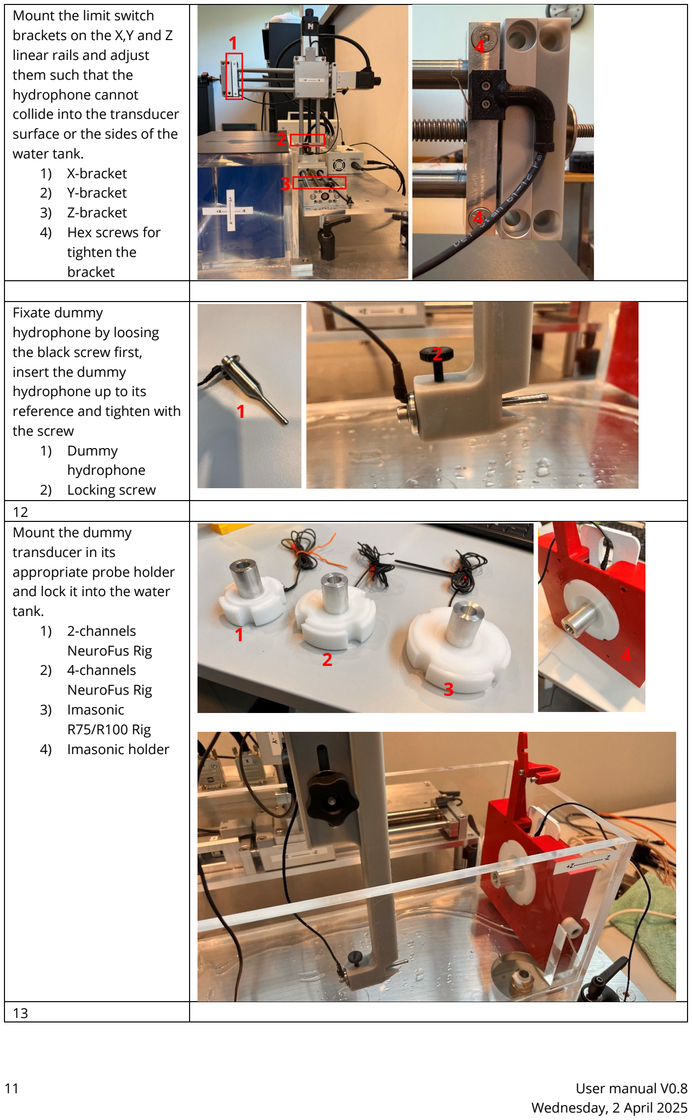
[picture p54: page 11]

Mount the limit switch
brackets on the X,Y and Z
linear rails and adjust
them such that the
hydrophone cannot
collide into the transducer surface or the sides of the water tank.
1) X-bracket
2) Y-bracket
3) Z-bracket
4) Hex screws for
tighten the
bracket
Fixate dummy hydrophone by loosing the black screw first, insert the dummy hydrophone up to its reference and tighten with the screw 1) Dummy hydrophone 2) Locking screw | 2 1

12
Mount the dummy
transducer in its
appropriate probe holder
and lock it into the water tank.
1) 2-channels
NeuroFus Rig
2) 4-channels
NeuroFus Rig
3) Imasonic
R75/R100 Rig
4) Imasonic holder

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
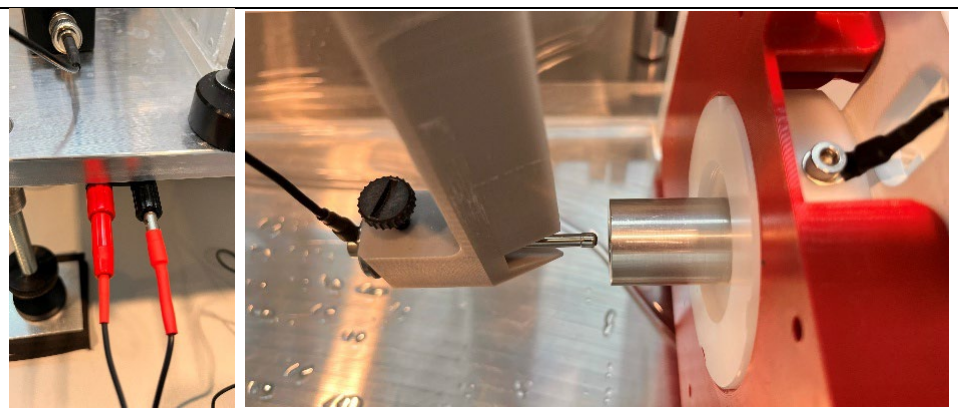
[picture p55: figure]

Turn on the XYZ stage switch. Connect both wires to the socket in front of the base plate Run the “XYZ probing” sequence (see paragraph 3.3). Note the values and (need to be used before acoustical alignment) After the initial absolute coordinates are estimated, remove the dummy hydrophone and transducer from there respected brackets

14
Connect the output pump
side to the left input of
the water tank and the
input tank to a container
with demi-water supply.
Turn on the pump and
degassing while filling up the tank. When filled
completely, remove the
input hose from the
container and lock them
to the bottom connector
of the water tank.
1) Water tank input
2) Water tank
output

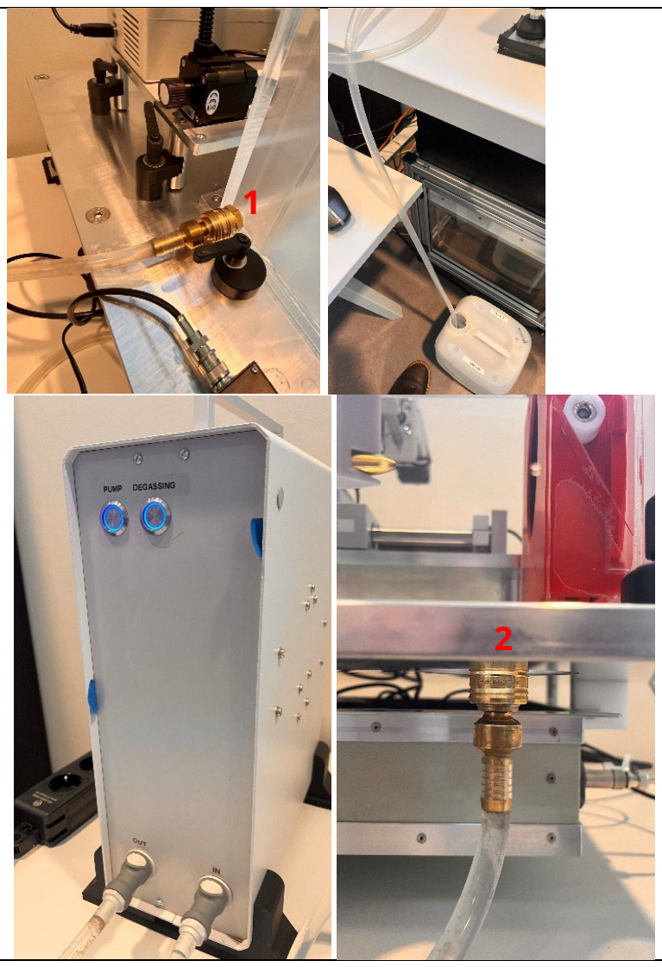
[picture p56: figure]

## 3.2 Pre-measurement setup instructions

After successfully completing the initial setup and calibration steps described in this manual, it's essential to perform specific preparation actions before each measurement session. These routine actions ensure optimal measurement accuracy, reproducibility, and reliability by maintaining consistent environmental conditions and system performance.

- Check Environmental Conditions:
Confirm water temperature, purity, and dissolved gas levels meet recommended criteria
- Inspect Positioning System:
Ensure all stage movements are functioning smoothly and verify the positioning accuracy.
- System Warm-up and Stability:
Allow sufficient warm-up time for all electronic measurement equipment, stabilizing electrical noise and drift. It is recommended to let the hydrophone acclimatize in the water for some time.

Performing these steps routinely before each measurement session guarantees precise and consistent results, significantly enhancing the overall reliability of your acoustic characterization process.

15

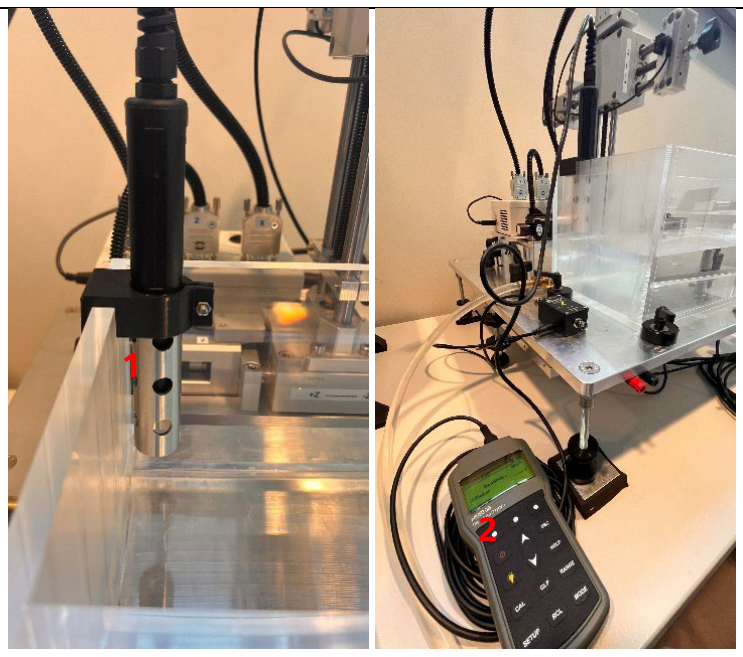
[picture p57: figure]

Place the dissolved oxygen measurement device in the water and start measuring the concentration oxygen. Remain pumping and degassing until the desired (<4mg/L) concertation has reached. Shut down the pump and repeat degassing upon undesired levels due to natural oxygenation of the water. 1) Dissolved oxygen and temperature probe 2) Portable readout | 1 2

16

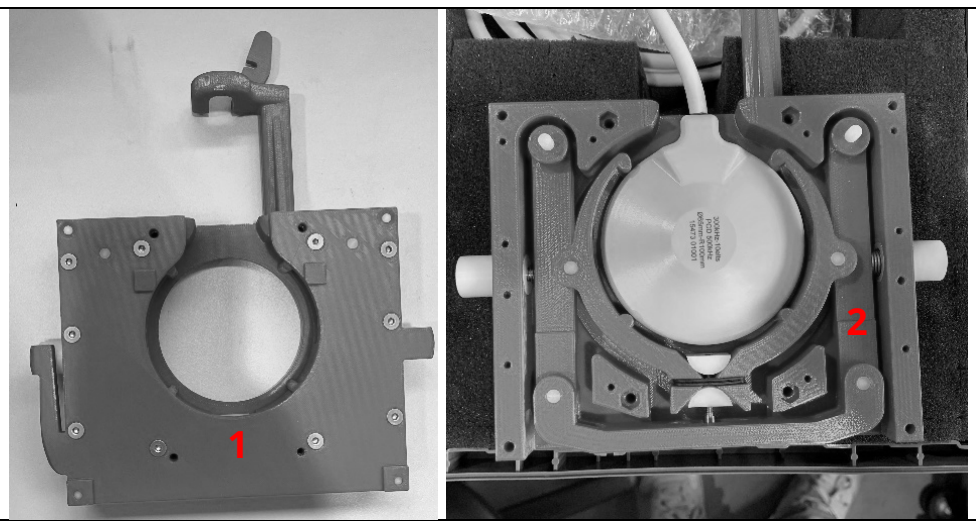
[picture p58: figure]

Mount the transducer in the designated probe holder. 1) Probe holder 2) Inner body to manipulate probe center 3) Fixation bracket 4) Transducer specific offset ring | 2 1

| 3 4

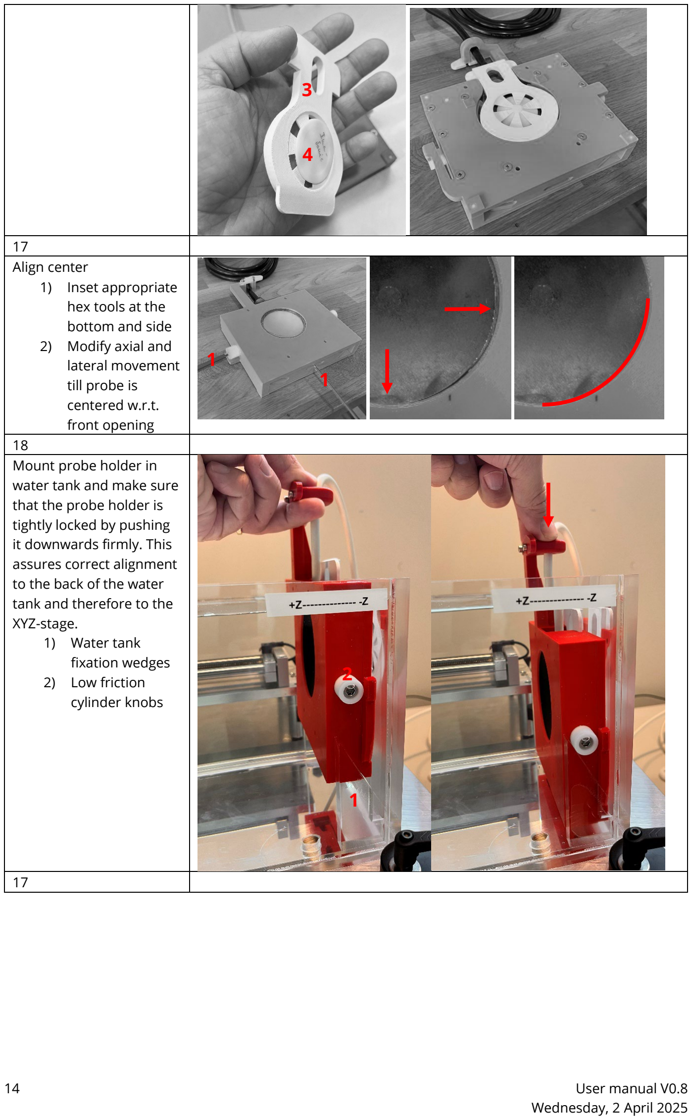
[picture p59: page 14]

Mount probe holder in
water tank and make sure
that the probe holder is
tightly locked by pushing
it downwards firmly. This
assures correct alignment
to the back of the water
tank and therefore to the
XYZ-stage.
1) Water tank
fixation wedges
2) Low friction
cylinder knobs

17

17
Align center 1) Inset appropriate hex tools at the bottom and side 2) Modify axial and lateral movement till probe is centered w.r.t. front opening

18

1
1

1

2

1

2

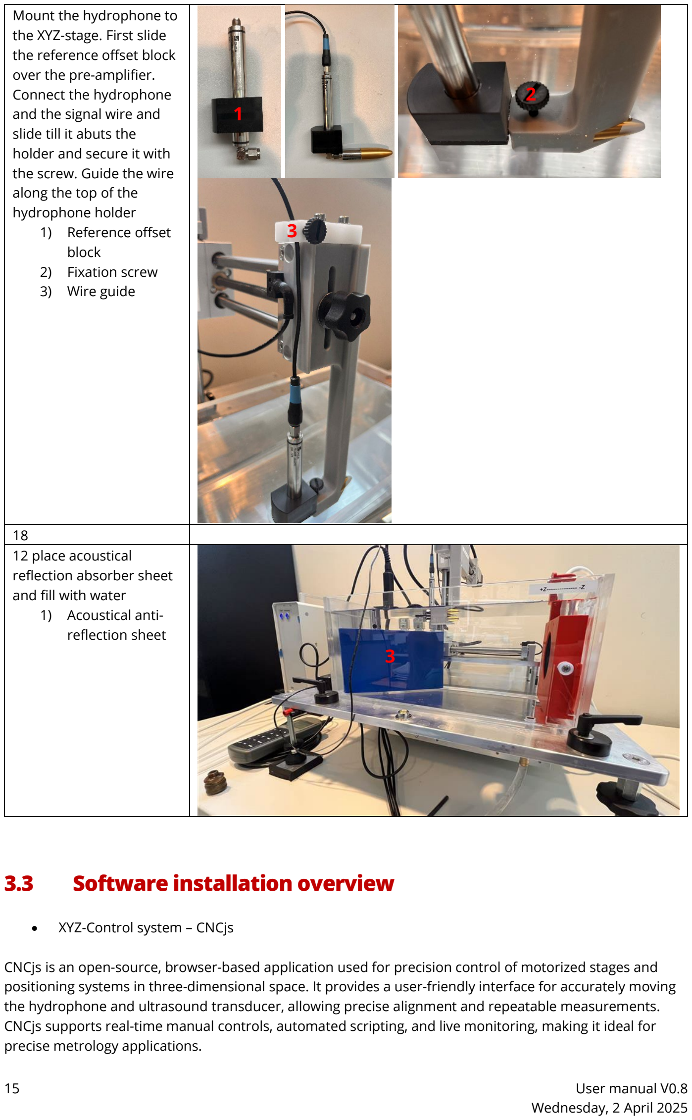
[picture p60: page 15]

Mount the hydrophone to
the XYZ-stage. First slide the reference offset block over the pre-amplifier.
Connect the hydrophone
and the signal wire and
slide till it abuts the
holder and secure it with
the screw. Guide the wire
along the top of the
hydrophone holder
1) Reference offset
block
2) Fixation screw
3) Wire guide

18
12 place acoustical reflection absorber sheet and fill with water 1) Acoustical anti-reflection sheet | 3

## 3.3 Software installation overview

- XYZ-Control system – CNCjs

CNCjs is an open-source, browser-based application used for precision control of motorized stages and positioning systems in three-dimensional space. It provides a user-friendly interface for accurately moving the hydrophone and ultrasound transducer, allowing precise alignment and repeatable measurements. CNCjs supports real-time manual controls, automated scripting, and live monitoring, making it ideal for precise metrology applications.

3

Download and Documentation: https://cnc.js.org. Make sure that the right com port is selected for successful serial communication.

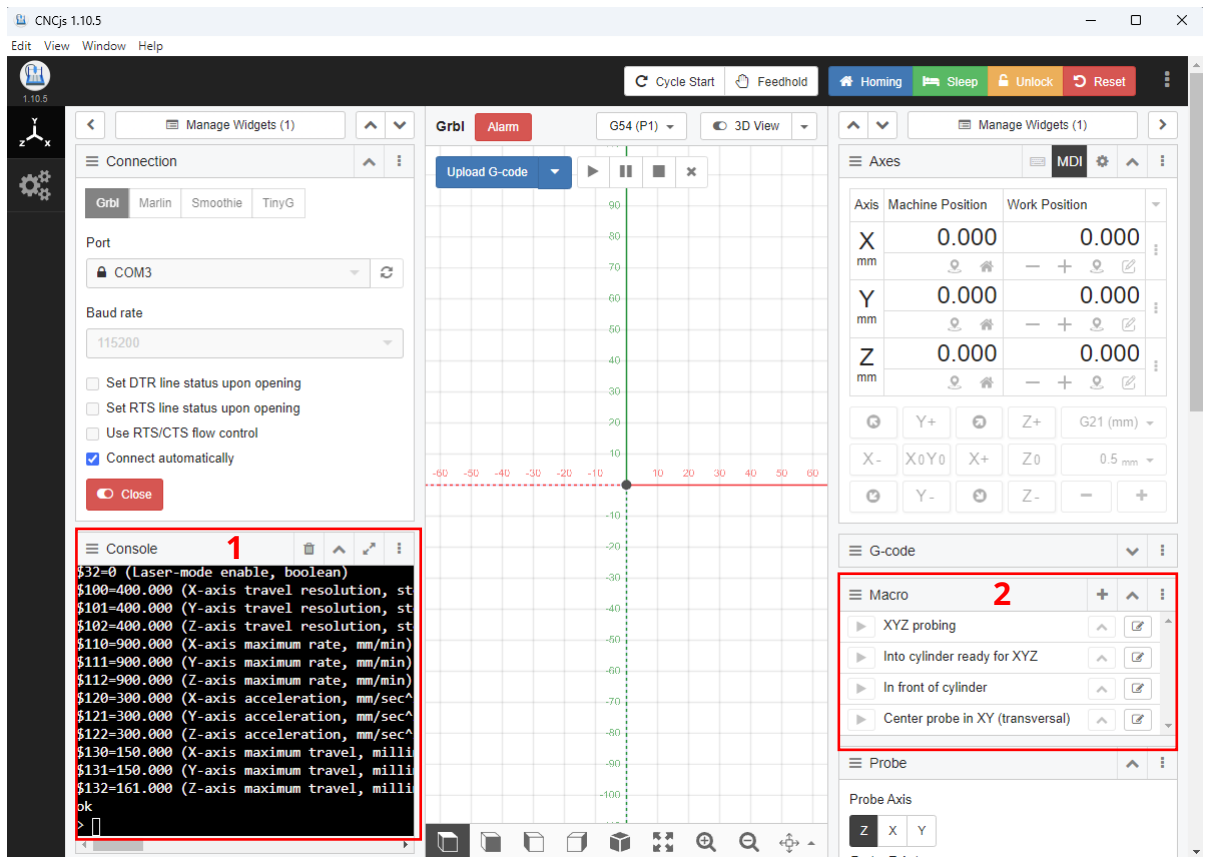
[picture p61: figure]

CNCJS
1) Set the correct stage parameters with “$” command to match:

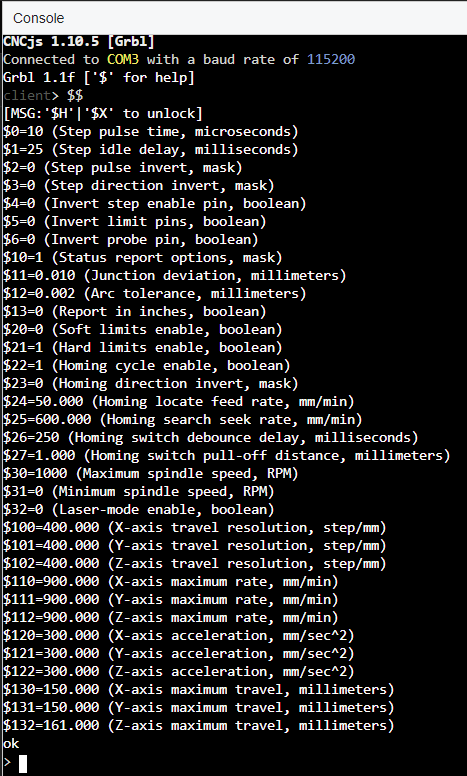
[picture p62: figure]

2) Import a macro “XYZ probing” (see appendix) and make sure that the center of the acoustical axes is X-63.5 Y-62.0 w.r.t. the homing position determined by the end stops.

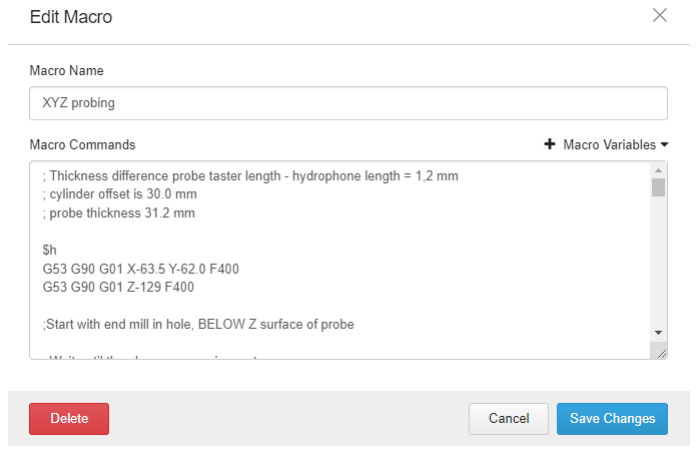
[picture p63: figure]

3)
4) Start the XYZ probing procedure to finally measure the X, Y and Z coordinate to use for the initial alignment procedure (see manual driving system software). In case of physical changes e.g., water tank replacement, please re-do this mechanical exit plane probing and set the correct initial values for the acoustical alignment. Please note that the initial mechanical alignment is the only input for the Z/axial coordinate. The X and Y are fine tuned using the axial alignment procedure ran before each measurement.

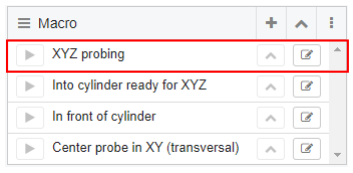
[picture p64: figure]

- Python IDE and manuals please refer to
- https://github.com/Donders-Institute/Radboud-FUS-measurement-kit/blob/release/README.md (https://github.com/Donders-Institute/Radboud-FUS-measurement-kit/blob/release/README.md)
- https://github.com/Donders-Institute/Radboud-FUS-driving-system-software/blob/release/README.md (https://github.com/Donders-Institute/Radboud-FUS-driving-system-software/blob/release/README.md)

# 4 Appendix

## 4.1 Macro for center exit plane probing

Please copy the below text into the Macro Commands field

Thickness difference probe taster length - hydrophone length = 1,2 mm ; cylinder offset is 30.0 mm
; probe thickness 31.2 mm

$h
G53 G90 G01 X-63.5 Y-62.0 F400
G53 G90 G01 Z-129 F400

;Start with end mill in hole, BELOW Z surface of probe

; Wait until the planner queue is empty
%wait

; Set user-defined variables
%Z_PROBE_THICKNESS = 31.2 ;thickness of Z probe plate %PROBE_DISTANCE = 10 ;Max distance for a probe motion %PROBE_FEEDRATE_A = 100
%PROBE_FEEDRATE_B = 25
%PROBE_MAJOR_RETRACT = 1 ;distance of retract before probing opposite side %Z_PROBE = 15 ; Lift out of hole and Max Z probe
%Z_PROBE_KEEPOUT = 2 ;distance (X&Y) from edge of hole for Z probe %Z_FINAL = 5 ;final height above probe

%UNITS=modal.units
%DISTANCE=modal.distance

G91 ; Relative positioning
G21 ;Use millimeters

; Probe toward right side of hole with a maximum probe distance G38.2 X[PROBE_DISTANCE] F[PROBE_FEEDRATE_A]
G0 X-2 ;retract 2mm
G38.2 X5 F[PROBE_FEEDRATE_B] ;Slow Probe
%X_RIGHT = posx
G0 X-[PROBE_MAJOR_RETRACT] ;retract

; Probe toward Left side of hole with a maximum probe distance G38.2 X-[PROBE_DISTANCE] F[PROBE_FEEDRATE_A]
G0 X2 ;retract 2mm
G38.2 X-5 F[PROBE_FEEDRATE_B] ;Slow Probe
%X_LEFT = posx
%X_CHORD = X_RIGHT - X_LEFT
G0 X[X_CHORD/2]

%X_CENTER = posx ;get X-value of hole center for some reason ; A dwell time of one second to make sure the planner queue is empty G4 P1
G10L20X0

; Probe toward top side of hole with a maximum probe distance G38.2 Y[PROBE_DISTANCE] F[PROBE_FEEDRATE_A]
G0 Y-2 ;retract 2mm
G38.2 Y5 F[PROBE_FEEDRATE_B] ;Slow Probe
%Y_TOP = posy
G0 Y-[PROBE_MAJOR_RETRACT] ;retract
; Probe toward bottom side of hole with a maximum probe distance G38.2 Y-[PROBE_DISTANCE] F[PROBE_FEEDRATE_A]
G0 Y2 ;retract 2mm
G38.2 Y-5 F[PROBE_FEEDRATE_B] ;Slow Probe
%Y_BTM = posy
%Y_CHORD = Y_TOP - Y_BTM
%HOLE_RADIUS = Y_CHORD/2
G0 Y[HOLE_RADIUS]
%Y_CENTER = posy ;get Y-value of hole center
; A dwell time of one second to make sure the planner queue is empty G4 P1
G10L20Y0

;Get to Z probe location
G0 Z[Z_PROBE]
X[HOLE_RADIUS + Z_PROBE_KEEPOUT] Y[HOLE_RADIUS + Z_PROBE_KEEPOUT]

; Probe Z
G38.2 Z-[Z_PROBE] F[PROBE_FEEDRATE_A]
G0 Z2 ;retract 2mm
G38.2 Z-5 F[PROBE_FEEDRATE_B] ;Slow Probe G10L20Z[Z_PROBE_THICKNESS]
G0 Z[Z_FINAL] ;raise Z
G90 ;absolute distance
G0 X0 Y0
; A dwell time of one second to make sure the planner queue is empty G4 P1

[UNITS] [DISTANCE] ;restore unit and distance modal state
$h home dummy hydrophone

# 5 Changelog

## 5.1 Version history

March 2025 | Initial version

# 6 Contact / Support

For direct contact: fus@ru.nl

## 6.1 Links to repository or project page (e.g., GitHub)

Resources (Solid
works & Step
files)

https://github.com/Donders-Institute/Radboud-FUS-measurement-kit/tree/release/SonoRover%20One/hardware

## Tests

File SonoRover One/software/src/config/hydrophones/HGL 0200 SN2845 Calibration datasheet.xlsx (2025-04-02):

Freq(MHz) | Sens(V/Pa)
0.25 | 2.295e-07
0.30 | 2.717e-07
0.35 | 2.627e-07
0.40 | 2.683e-07
0.45 | 2.657e-07
0.50 | 2.542e-07
0.55 | 2.51e-07
0.60 | 2.467e-07
0.65 | 2.436e-07
0.70 | 2.365e-07
0.75 | 2.268e-07
0.80 | 2.218e-07
0.85 | 2.141e-07
0.90 | 2.052e-07
0.95 | 1.977e-07
1.00 | 1.893e-07

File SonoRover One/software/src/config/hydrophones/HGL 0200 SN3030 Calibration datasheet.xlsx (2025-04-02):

Freq(MHz) | Sens(V/Pa)
0.25 | 3.88e-07
0.30 | 4.336e-07
0.35 | 4.116e-07
0.40 | 4.171e-07
0.45 | 4.126e-07
0.50 | 4.005e-07
0.55 | 4.01e-07
0.60 | 3.978e-07
0.65 | 3.91e-07
0.70 | 3.817e-07
0.75 | 3.652e-07
0.80 | 3.6e-07
0.85 | 3.478e-07
0.90 | 3.372e-07
0.95 | 3.22e-07
1.00 | 3.076e-07

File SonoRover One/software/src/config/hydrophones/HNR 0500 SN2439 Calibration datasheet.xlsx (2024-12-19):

Freq(MHz) | Sens(V/Pa)
0.25 | 0
0.30 | 0
0.35 | 0
0.40 | 0
0.45 | 0
0.50 | 0
0.55 | 0
0.60 | 0
0.65 | 0
0.70 | 0
0.75 | 0
0.80 | 0
0.85 | 0
0.90 | 0
0.95 | 0
1.00 | 0

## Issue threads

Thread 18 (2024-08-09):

Add a timer to know how far along the process is

MaCuinea, 2024-08-09:

MaCuinea, 2025-01-13:
Use eta in current print statements stating the amount of measurements to go.  Calculate rate over first n measurement and estimate duration. Update this estimate over time.

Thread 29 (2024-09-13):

Complement Hydrophone calibration data log

StefFek-GIT, 2024-09-13:
Hey Margely,

Met de komst van meerdere hydrophones en ook nog eens verschillende calibratie data wordt het erg belangrijk om te weten met welke je nu te maken hebt.

We loggen nu wel het type maar nog niet de calibratie specifieke timestamp buiten een algemene timestamp. Mijn voorstel is dit toe te voegen aan de ini. Benende een voorstel om toe te voegen aan de .ini

Wat denk jij?

Thanks
S.

[Hydrophone]
Type = HGL
Aperture = 0200
Serial number = 2845
Amp model = AG2010
Amp serial number = 1378
Date of purchase = 2024-XX-XX
First calibration date = 2024-06-11
Last calibration date = 2024-06-11
Calibration company = Onda
Calibration iteration = 1
Current calibration data file name = HGL0200−2845_AG2010−1378−20_CA_20230511.txt

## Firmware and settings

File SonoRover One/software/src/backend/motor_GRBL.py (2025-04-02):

# -*- coding: utf-8 -*-
"""
Copyright (c) 2024 Margely Cornelissen, Stein Fekkes (Radboud University) and Erik Dumont (Image
Guided Therapy)

MIT License

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
**Attribution Notice**:
If you use this kit in your research or project, please refer to the 'How to Cite' section in the
README.md file of https://github.com/Donders-Institute/Radboud-FUS-measurement-kit.
"""

import serial
import serial.tools.list_ports as list_ports
import sys
import time
import re

# Own packages
# Access the logger
from config.logging_config import logger
from config.config import config_info as config
from backend.utils import get_config_value


MotorErrorCode = {
0 : 'Connection Error',
1 : 'Initialization Error',
2 : 'Range Error',
3 : 'Motor Firmware error',
4 : 'Undefined Error',
}


class MotorError(Exception):
    def __init__(self, code=0, message="MotorError"):
        self.code = code
        self.message = message
        super().__init__(self.message)

    def __str__(self):
        return f'Motor error {self.code}: {self.message}'

class MotorsXYZ:
    """
    class to communicate with the motors at baudrate speed
    """
    def __init__(self, baudrate=115200, timeout=4):
        self._timeout = timeout
        self._baudrate = baudrate
        self._current_position =[-1.0,-1.0,-1.0]
        self._com_port = None ## self.scan_serial_ports()
        self.connected = False
        self._homed = False
        self.initialized = False
        self.ready = False
        self._busy = False
        self._alarm = False
        self.rangeXYZ = [0.0,0.0,0.0]
        self._axisLetter = [ 'X','Y', 'Z' ]
        self._last_move_duration = 0.0
        self._com = None
        self.com_port = None


    def _parse_hwid(self,hwid):
        dev=hwid.split()[0]
        nameVID = 'VID:PID='
        len_nameVID = len(nameVID)
        debVID =hwid.find('VID:PID=')+len_nameVID
        vid = hwid[debVID:debVID+4]
        pid = hwid[debVID+5:debVID+9]
##        print(f'hwid={hwid}')
##        print(f'vid={vid},pid={pid}')
        return dev,vid,pid


    def detect_com(self):
        finished=False
        error = False
        ok =False
        all_port_tuples = list_ports.comports()
        logger.debug(all_port_tuples)
        for port,desc, hwid in all_port_tuples:
            dev,vid,pid = self._parse_hwid(hwid)
            logger.debug(f"port={port}\ndesc={desc}\ndev:{dev}, vid={vid},pid={pid}")
            if dev=='USB' and vid=='2341' and (pid=='0043' or pid=='0042'): # ARDUINO
                return port
        return None

    def connect(self, port='com11'):
        finished=False
        error = False
        ok =False
        if port: # port not None
            start_time=time.time()
            tooLong = False
            ser = serial.Serial(port, self._baudrate, timeout=self._timeout)
            line1=ser.readline()
            line2=ser.readline().decode('ascii',errors='ignore').strip().upper()
            # print('second lines', line2)
            if line2.startswith('GRBL'):
                line3=ser.readline().decode('ascii',errors='ignore').strip()
                if line3[:1]=='[':
                    ok = True
                    self._com = ser
                    self.com_port = port
                    self.connected =True
                    logger.debug('connected: {}, port: {}'.format(self.connected,port))
            else:
                ser.close()
        else:
            message = 'error, no port detected'
            logger.critical(message)
            sys.exit(message)
        logger.debug(f'ok: {ok} - error: {error} - tooLong: {tooLong} - Motor' +
                     f' connected: {self.connected}')


    def _send_cmd(self,cmd):
        self._com.reset_output_buffer()
        self._com.reset_input_buffer()
        cmd+='\n'
        self.nb=self._com.write(cmd.encode('ascii'))

    def _read_ans(self,timeout=1):
        finished=False
        start_time=time.time()
        ans = ''
        while ( not finished ):
            line=self._com.readline().decode('ascii').strip()
            if line == 'ok':
                ok=True
                break
            else:
                ans = line
            finished = (time.time()-start_time)>timeout
        return ans

    def _read_params(self,timeout=4):
        ok = False
        if self.connected:
            self._busy = True
            finished=False
            start_time=time.time()
            cmd_params="$$"
            self._send_cmd(cmd_params)
            while ( not finished ):
                line=self._com.readline().decode('ascii').strip()
                if line == 'ok':
                    ok=True
                    break
                variable, value = line.split('=')
                if variable == '$130':
                    self.rangeXYZ[0]=float(value)
                if variable == '$131':
                    self.rangeXYZ[1]=float(value)
                if variable == '$132':
                    self.rangeXYZ[2]=float(value)
                finished = (time.time()-start_time)>timeout
        return ok

    def initialize(self):
        if not self.initialized:
            self.home()
            logger.debug('initialize')
            self._send_cmd('G91')
            ok=self._wait_for_ok()
            self._send_cmd('G21')
            self._wait_for_ok()
            self._send_cmd('F900')
            self._wait_for_ok()
            ok=self._read_params()
            logger.debug('rangeXYZ: {}'.format(self.rangeXYZ))
            if ok and not self._alarm:
                self.initialized = True
                self.ready = True
                self._send_cmd('$G')
                logger.debug(f'state: {self._read_ans()}')

    def home(self,axis=['X','Y', 'Z'], together=True):
        logger.debug('homing: $H')
        if self.connected:
            self._busy = True
            cmd_home="$H"
            if together:
                self._send_cmd(cmd_home)
                logger.debug(f'cmd_home: {cmd_home}')
                self._wait_for_ok(timeout=30)
            else:
                for axe in axis:
                    if axe in {'X','Y', 'Z'}:
                        cmd_home_axe = cmd_home + ' ' + axe
                        self._send_cmd(cmd_home_axe)
                        self._wait_for_ok(timeout=20)
            self.readPosition()
            self._busy = False
            if self._current_position[0]>= 0.0 and self._current_position[1]>= 0.0 and self._current_position[2]>= 0.0:
                self._homed=True
            else:
                self.raise_exception(1)
        else:
            self.raise_exception(0)

        # Reset zero to prevent error
        self.zero()

    def zero(self):
            logger.debug('zeroing: G10 P0 L20 X0 Y0 Z0')
            self._send_cmd('G10 P0 L20 X0 Y0 Z0')
            self._wait_for_ok()

    def readPosition(self, forceRead=True, attempt = 0):
        if (forceRead):
            self._send_cmd("?")
            status_answer=self._com.readline()
            line = status_answer.decode('ascii')
            logger.debug('readPos: ' + line)
            
            try:
                split_str=re.split("[,:|]+", line[1:])
                self.status = split_str[0]
                mpos = split_str[1]
                self._current_position = [float(x) for x in split_str[2:5]]
            except:
                logger.debug('split_str: ' + ' '.join(split_str))
                logger.debug('Reading position failed. Try again.')

                max_attempts = int(get_config_value(logger, config, 'Characterization',
                                                    'pos_sys.reacquire_attempts', 5))
                if attempt < max_attempts:
                    self.readPosition(attempt = attempt + 1)
                else:
                    message = 'Reading position failed multiple times. Quitting.'
                    logger.critical(message)
                    sys.exit(message)
                
            self._wait_for_ok()
            msg = "Read current_position: {} ".format(self._current_position)
            logger.debug(msg)
        return self._current_position

    def _wait_for_ok(self,timeout=1):
        start_time=time.time()
        finished=False
        ok = False
        while ( not finished ):
            line=self._com.readline().decode('ascii').strip()
            logger.debug('line: {}'.format(line))
            if line == 'ok':
                ok=True
                break
            if line.upper().startswith('ERROR') or line.upper().startswith('ALARM'):
                self._alarm= True
                break
            finished = (time.time()-start_time)>timeout
        logger.debug('ok: {}'.format(ok))
        return ok

    def _wait_for_done(self,timeout=30):
        done=False
        if(self._wait_for_ok()):
            start_time=time.time()
            finished=False
            self._send_cmd('G4 P0')
            if(self._wait_for_ok(timeout=timeout)):
                done=True
        logger.debug('done: {}'.format(done))
        return done

    def wait_for_idle(self,timeout=30):
        start_time=time.time()
        finished=False
        ok = False
        while ( not finished ):
            pos=self.readPosition()
#            logger.debug('position: {:.3f}, {:.3f}, {:.3f} ; status: {}'.format(*pos,self.status))
            if self.status == 'Idle':
                ok=True
            time.sleep(0.05)
            timeout_error = (time.time()-start_time)>timeout
            finished = timeout_error or ok
        logger.debug('finished wait_for_idle; ok: {}, timeout_error: {}'.format(ok, timeout_error))
        return ok

    def moveAsync(self, XYZ, relative = True):
        if not self.ready:
            raise MotorError(message="Motor not ready.")
        if relative:
            offsetXYZ=XYZ
            targetXYZ = [x+y for x,y in zip(self._current_position,offsetXYZ)]
        else:
            targetXYZ = XYZ
            offsetXYZ = [x-y for x,y in zip(targetXYZ,self._current_position)]
        logger.debug('target: {:.3f},{:.3f},{:.3f}; offset: {:.3f},{:.3f},{:.3f}'.format(*targetXYZ,*offsetXYZ))
        if self.isWithinRange(targetXYZ):
            offset = [round(x,3) if abs(x)>0.005 else 0.0 for x in offsetXYZ]
            move_cmd = 'G1 '
            for axe in range(len(offset)):
                if abs(offset[axe])>0.0:
                    move_cmd += "{}{:.3f}".format(self._axisLetter[axe], offset[axe])
            logger.debug('offset: {}, move_cmd: {}'.format(offset,move_cmd))
            self._send_cmd(move_cmd)
            ok=self._wait_for_ok()
            if not ok:
                raise MotorError(message="error in motion: {}".format(move_cmd))
            self.readPosition()
        else:
            raise MotorError(message="motion out of range: {}".format(targetXYZ))

    def move(self, XYZ, relative = True):
        if not self.ready :
            raise MotorError(message="Motor not ready.")
        if relative:
            offsetXYZ=XYZ
            targetXYZ = [x+y for x,y in zip(self._current_position,offsetXYZ)]
        else:
            targetXYZ = XYZ
            offsetXYZ = [x-y for x,y in zip(targetXYZ,self._current_position)]
        if self.isWithinRange(targetXYZ):
            offset = [round(x,3) if abs(x)>0.005 else 0.0 for x in offsetXYZ]
            move_cmd = 'G1'
            for axe in range(len(offset)):
                if abs(offset[axe])>0.0:
                    move_cmd += " {}{:.3f}".format(self._axisLetter[axe], offset[axe])
            logger.debug('offset: {}, move_cmd: {}'.format(offset,move_cmd))
            self._send_cmd(move_cmd)
            ok=self._wait_for_ok()
            done=self.wait_for_idle()
            if not done:
                raise MotorError(message="error in motion: {}".format(move_cmd))
            self.readPosition()
        else:
            raise MotorError(message="motion out of range: {}".format(targetXYZ))

    def isWithinRange(self,destXYZ):
        ok = True
        for i in range(len(destXYZ)):
            ok = ok and -1*self.rangeXYZ[i]<=destXYZ[i]<=0.0
        return ok

    def print_ans(self):
        for line in self.ans:
            print(line.decode('ascii'))

    def raise_exception(self,i):
        raise MotorError(i, MotorErrorCode[i])


    def disconnect(self):
        self.connected = False
        self._homed = False
        self.initialized = False
        self.ready = False
        self._com.close()


def test_parse_pos():
    line='<Idle|MPos:10.000,0.000,0.000|FS:0,0|WCO:0.000,0.000,0.000>'
    split_str=re.split("[,:|]+", line[1:])
    print(split_str)
    status = split_str[0]
    mpos = split_str[1]
    currentPos = [float(x) for x in split_str[2:5]]
    print('status: {}, MPos: {}, X: {:.3f},  Y: {:.3f}, Z: {:.3f}'.format(status,mpos,*currentPos))


def main():
    myMotor = MotorsXYZ('')
    myMotor.logger.info(myMotor.com_port)
    port=myMotor.detect_com()
    myMotor.logger.info(port)
    try:
        myMotor.connect()
        myMotor.initialize()
        myMotor._read_params()
        myMotor.logger.info('myMotor.rangeXYZ: ', myMotor.rangeXYZ)
        myMotor.logger.info('myMotor.currentPos: ', myMotor.readPosition(forceRead=False))
        myMotor.logger.info('myMotor.initialized: ', myMotor.initialized)
        myMotor.move([17.35,24.45,12.21], relative=False)
        myMotor.move([-2.0,+4.0,-3.50])
    finally:
        myMotor.disconnect()
##    print("is in range 10.0,10.0,200.1: ",myMotor.isWithinRange([10.0,10.0,200.1]))
##    print("is in range -0.1,200.0,199.0: ",myMotor.isWithinRange([-0.1,200.0,199.0]))
##    print("is in range -0.0,200.0,199.0: ",myMotor.isWithinRange([-0.0,200.0,199.0]))
##    myMotor.moveAbs([17.35,24.45,12.21])
##    myMotor.moveAbs([8.18,32.71,15.49])
##    myMotor.moveRel([-2.0,+4.0,-3.50])
##    myMotor.moveAbs([30.0,40.0,200.1])
##    for i in range(5):
##        try:
##                myMotor.raise_exception(i)
##        except MotorError as e:
##            print('except MotorError {}: {}'.format(e.code,e.message))


if __name__ == '__main__':
##    test_parse_pos()
    main()

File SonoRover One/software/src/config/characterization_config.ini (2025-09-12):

[General]
maximum number of output filename = 1000

[Logging]
logger name = SonoRover_One
timestamp format = %Y-%m-%d_%H-%M-%S
log level console = WARNING
log level file = DEBUG
initial part of log filename = log_

[Versions]
sonorover one software = 1.3.0

[Characterization]
path of input parameters cache = config//characterization_input_cache.ini
cache date format = %Y/%m/%d
temporary output path = C:\Temp\General output folder
temporary logging path = C:\Temp\General output folder\logs
default protocol directory = //ru.nl//WrkGrp//FUS_Hub//Hydrophone measurements//Measurements
default output directory = //ru.nl//WrkGrp//FUS_Hub//Hydrophone measurements//Measurements//2024//General output folder
disconnection message = Ensure the following: 
	 - PicoScope software is not connected to the PicoScope in use. 
	 - Universal Gcode Sender is not connected to the positioning system.
continue acquisition message = Continue acquisition with the following sequence: 
acd adjustment.zero = 0 - no adjustment
acd adjustment.plus = +1 - axial measurement moving from transducer
acd adjustment.min = -1 - axial measurement moving towards transducer
acd adjustment = 0 - no adjustment
	+1 - axial measurement moving from transducer
	-1 - axial measurement moving towards transducer
protocols = Select protocol excel file...
	Acoustical alignment
protocol.excel = Select protocol excel file...
protocol.ac_align = Acoustical alignment
output_name_suffix = output_data
ac_align.output_name_suffix = output_data
ac_align.axis_suffix = acoustical_axis
ac_align.additional_x_lim = 15
protocol_dialog.n_ac_align_rows = 14
protocol_dialog.stay_topmost_in_ms = 5000
input_dialog.stay_topmost_in_ms = 5000
acd_dialog.stay_topmost_in_ms = 5000
coord_excel_columns.meas_num = Measurement number
coord_excel_columns.clus_num = Cluster number
coord_excel_columns.ind_num = Indices number
coord_excel_columns.x_coord = X-coordinate [mm]
coord_excel_columns.y_coord = Y-coordinate [mm]
coord_excel_columns.z_coord = Z-coordinate [mm]
coord_excel_columns.row = Row number
coord_excel_columns.col = Column number
coord_excel_columns.sl = Slice number
coord_excel_columns.abs_x_coord = Absolute X-coordinate [mm]
coord_excel_columns.abs_y_coord = Absolute Y-coordinate [mm]
coord_excel_columns.abs_z_coord = Absolute Z-coordinate [mm]
coord_excel_columns = Measurement number
	Cluster number
	Indices number
	X-coordinate [mm]
	Y-coordinate [mm]
	Z-coordinate [mm]
	Row number
	Column number
	Slice number
	Absolute X-coordinate [mm]
	Absolute Y-coordinate [mm]
	Absolute Z-coordinate [mm]
prot_excel_columns.seq_num = Sequence number
prot_excel_columns.tag = Tag
prot_excel_columns.dephasing = (De)phase array [degree] (None = no (de)phasing) ONLY FOR IGT DS
prot_excel_columns.pulse_dur = Pulse duration [us]
prot_excel_columns.pulse_rep_int = Pulse Repetition Interval [ms]
prot_excel_columns.power = SC - Global power [mW] or IGT - Max. pressure in free water [Mpa], Voltage [V] or Amplitude [%]
prot_excel_columns.power_value = Corresponding value
prot_excel_columns.focus_def = Focus definition
prot_excel_columns.focus_value = Focus value [mm]
prot_excel_columns.ramp_mode = Modulation
prot_excel_columns.ramp_dur = Ramp duration [us]
prot_excel_columns.excel_or_param = Coordinates based on excel file or parameters on the right?
prot_excel_columns.coord_excel = Path and filename of coordinate excel
prot_excel_columns.max_x_plus = max. + x [mm] w.r.t. relative zero
prot_excel_columns.max_x_min = max. - x [mm] w.r.t. relative zero
prot_excel_columns.max_y_plus = max. + y [mm] w.r.t. relative zero
prot_excel_columns.max_y_min = max. - y [mm] w.r.t. relative zero
prot_excel_columns.max_z_plus = max. + z [mm] w.r.t. relative zero
prot_excel_columns.max_z_min = max. - z [mm] w.r.t. relative zero
prot_excel_columns.dir_slices = direction_slices
prot_excel_columns.dir_rows = direction_rows
prot_excel_columns.dir_columns = direction_columns
prot_excel_columns.step_size_x = step_size_x [mm]
prot_excel_columns.step_size_y = step_size_y [mm]
prot_excel_columns.step_size_z = step_size_z [mm]
prot_excel.glob_pow = SC - Global power [mW] (fill in 'Corresponding value')
prot_excel.press = IGT - Max. pressure in free water [MPa] (fill in 'Corresponding value')
prot_excel.volt = IGT - Voltage [V] (fill in 'Corresponding value')
prot_excel.ampl = IGT - Amplitude [%] (fill in 'Corresponding value')
prot_excel.coord_excel = Coordinate excel file
prot_excel.grid_param = Parameters on the right
default.acq_time_us = 500
default.sampl_freq_multi = 50
default.pos_com_port = COM3
default.temp = 
default.dis_oxy = 
default.x_coord_zero = -62.5
default.y_coord_zero = -61.0
default.z_coord_zero = -154.1
default.perform_all_seqs = True
default.distance_from_foc = 0
default.init_line_len = 30
default.init_line_step = 0.5
default.init_threshold = 0.01
default.reduction_factor = 0.5
default.max_red_iter = 5
default.create_graphs = True
default.y_lim = 200
default.create_axis_file = True
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

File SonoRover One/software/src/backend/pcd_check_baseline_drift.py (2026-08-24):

"""
Script to check drift relative to a baseline over time.

For each cluster:
1. Load the baseline (created by baseline_average.py).
2. Find all raw measurement files for that cluster.
3. Extract the measurement date from the filename (format: YYYYMMDD).
4. Compute the std of the residual (measurement - baseline) per file.
   -> This tells you how much that measurement deviates from the baseline.
5. Plot this deviation over time, so you can see whether it is
   increasing, decreasing, or fluctuating.

Note: if multiple files share the same date, their deviation values are
averaged for that date.
"""

import re
import numpy as np
import matplotlib.pyplot as plt
from pathlib import Path
from datetime import datetime

# ---------------- settings ----------------

input_folder = Path("data")       # folder containing all measurements (all clusters, all dates)
baseline_folder = Path("baselines\Imasonic_15287_1002_R75")   # folder containing the baseline files from baseline_average.py
dtype = np.float32                    # data type of the raw samples
output_folder = Path("drift_check")   # folder where the drift plots are written

# Cluster tags -> must appear somewhere in the filename (trailing "_" avoids elem_1 matching elem_10)
clusters = ["all_elems_"] + [f"elem_{i}_" for i in range(1, 11)]

equipment_name = "IS_PCD15287_01002_IGT-32-ch_comb_1x10-ch"

run_date = datetime.now().date().strftime("%Y-%m-%d")  # current date, no time

date_pattern = re.compile(r"(\d{4}-\d{2}-\d{2})_\d{2}-\d{2}-\d{2}")  # matches e.g. 2026-03-04_11-44-58
date_format = "%Y-%m-%d"


# --------------------------------------------


def extract_date(filename: str):
    match = date_pattern.search(filename)
    if not match:
        return None
    try:
        return datetime.strptime(match.group(1), date_format)
    except ValueError:
        return None


def check_drift(cluster_tag: str):
    # Baseline files use the same naming convention as the raw data, just in their own folder
    baseline_candidates = sorted(baseline_folder.glob(f"*{cluster_tag}*.raw"))
    if not baseline_candidates:
        print(f"  [SKIPPED] No baseline found for '{cluster_tag}' in '{baseline_folder}'")
        return
    if len(baseline_candidates) > 1:
        print(f"  [WARNING] Multiple baseline files found for '{cluster_tag}', using '{baseline_candidates[0].name}'")
    baseline_file = baseline_candidates[0]
    baseline = np.fromfile(baseline_file, dtype=dtype)

    files = sorted(input_folder.glob(f"*{cluster_tag}*.raw"))
    if not files:
        print(f"  [SKIPPED] No measurement files found for '{cluster_tag}'")
        return

    dates, devs = [], []
    for f in files:
        date = extract_date(f.name)
        if date is None:
            print(f"  [WARNING] Could not find a date in '{f.name}', skipping")
            continue

        signal = np.fromfile(f, dtype=dtype)
        if len(signal) != len(baseline):
            print(f"  [WARNING] '{f.name}' has a different length than the baseline, skipping")
            continue

        residual_std = np.std(signal - baseline)
        dates.append(date)
        devs.append(residual_std)

    if not dates:
        print(f"  [SKIPPED] No usable dated measurements for '{cluster_tag}'")
        return

    # Average deviation per date, in case of multiple files per date
    unique_dates = sorted(set(dates))
    avg_devs = [np.mean([d for dt, d in zip(dates, devs) if dt == u]) for u in unique_dates]

    print(f"{cluster_tag}: {len(unique_dates)} dates found")
    for u, d in zip(unique_dates, avg_devs):
        print(f"  - {u.date()}: std vs baseline = {d:.4g}")

    # Simple linear trend to describe the overall direction
    x = np.array([(u - unique_dates[0]).days for u in unique_dates])
    if len(x) >= 2:
        slope, intercept = np.polyfit(x, avg_devs, 1)
        rel_change = (slope * x[-1]) / avg_devs[0] if avg_devs[0] != 0 else 0
        if abs(rel_change) < 0.1:
            trend_label = "roughly stable / fluctuating"
        elif slope > 0:
            trend_label = "increasing (drifting away from baseline)"
        else:
            trend_label = "decreasing (converging towards baseline)"
    else:
        slope, trend_label = 0, "not enough dates to determine a trend"

    print(f"  -> trend: {trend_label}\n")

    # Plot
    output_folder.mkdir(parents=True, exist_ok=True)
    plt.figure(figsize=(10, 5))
    plt.plot(unique_dates, avg_devs, marker="o", color="red", label="std vs baseline")
    if len(x) >= 2:
        plt.plot(unique_dates, slope * x + intercept, linestyle="--", color="gray", label="linear trend")
    plt.title(f"{equipment_name}\nCluster '{cluster_tag}': deviation from baseline over time\nTrend: {trend_label}")
    plt.xlabel("Date")
    plt.ylabel("Std of (measurement - baseline)")
    plt.legend()
    plt.xticks(rotation=45)
    plt.tight_layout()
    plot_file = output_folder / f"{run_date}_{cluster_tag}of_{equipment_name}_drift.png"
    plt.savefig(plot_file, dpi=150)
    plt.close()
    print(f"  -> drift plot saved to '{plot_file}'\n")


def main():
    for cluster_tag in clusters:
        check_drift(cluster_tag)


if __name__ == "__main__":
    main()

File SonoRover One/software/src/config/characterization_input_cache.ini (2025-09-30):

[Input parameters]
date = 2025/09/03
temporary output path = C:\Temp\General output folder\Output of T [Imasonic 10 ch. PCD15287_01001 ROC 75 mm] - DS [IGT 32 ch. - 1 x 10 ch.]\P [Acoustical alignment]
output path = C:/Temp/test_ac_align
driving system.serial_number = IGT-32-ch_comb_1x10-ch
driving system.name = IGT 32 ch. - 1 x 10 ch.
driving system.manufact = IGT
driving system.available_ch = 10
driving system.connect_info = igt\config\gen_Nijmegen32_10c_71D8_10W.json
driving system.tran_comp = IS_PCD15287_01001, IS_PCD15287_01002, IS_PCD15473_01001, IS_PCD15473_01002, IS_PCD15473_01003, IS_PCD15473_01001_OPM, IS_PCD15473_01003_OPM, Dummy
driving system.is_active = True
transducer.serial_number = IS_PCD15287_01001
transducer.name = Imasonic 10 ch. PCD15287_01001 ROC 75 mm
transducer.manufact = Imasonic
transducer.elements = 10
transducer.fund_freq_khz = 300
transducer.natural_foc_mm = 75.0
transducer.min_foc_mm = 5.32
transducer.max_foc_mm = 92.17
transducer.steer_info = igt\config\imasonic_transducers\transducer_15287_10_300kHz.ini
transducer.is_active = True
operating frequency [khz] = 300
com port of positioning system = COM3
hydrophone serial number = HGL 0200 SN3030
hydrophone name = Hydrophone HGL 0200 SN3030
hydrophone sensitivity (v/pa) datasheet = config//hydrophones//HGL 0200 SN3030 Calibration datasheet.xlsx
hydrophone acquisition time [us] = 500.0
picoscope serial number = 5442D
picoscope name = PicoScope 5442D - embedded in characterization setup
picoscope pico.py identification = 5442D
picoscope sampling frequency multiplication factor = 50.0
temperature of water [°c] = 22.0
dissolved oxygen level of water [mg/l] = 2.0
absolute g code x-coordinate of relative zero [mm] = -62.5
absolute g code y-coordinate of relative zero [mm] = -61.0
absolute g code z-coordinate of relative zero [mm] = -154.1
perform all sequences in sequence without waiting for user input? = True

[Input parameters.Protocol]
alignment.acoustical = True
alignment.pulse_dur_ms = 0.25
alignment.pulse_rep_int_ms = 20.0
alignment.power_option = Max. pressure in free water [MPa]
alignment.power_value = 1.0
alignment.chosen_focus = Focus wrt exit plane [mm]
alignment.focus_wrt_exit_plane_mm = [15.9]
alignment.focus_wrt_mid_bowl_mm = [array(26.36265427)]
alignment.distance_from_foc_mm = [0.0]
alignment.init_line_len_mm = 30.0
alignment.init_line_step_mm = 0.5
alignment.init_threshold = 0.01
alignment.reduction_factor = 0.5
alignment.max_red_iter = 5
alignment.create_graphs = True
alignment.y_lim_mv = 200.0
alignment.create_axis_file = True
alignment.axis_length_mm = 140.0
alignment.axis_stepsize_mm = 0.5

[Input parameters.ACD processing]
beginning time of processing window [us] = 0
end time of processing window [us] = 500.0
moving processing window along? = 0 - no adjustment

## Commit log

2024-05-21 example input coordinates and protocol
    [3D_3_1_120_2.csv, 3Dtestgrid.csv, Axial_0_01_140mm.csv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]
2024-05-21 start of software read me
    [template_protocol_input.xlsx]
2024-05-23 uploading version 0.8 code
    [CTX-250-001 - TPO-105-010 - Steer Table.xlsx, CTX-250-001 - TPO-203-035 - Steer Table.xlsx, CTX-250-009 - TPO-105-010 - Steer Table.xlsx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]
2024-05-23 add templates and modify readme
    [isppa_to_global_power_template.xlsx, template_protocol_input.xlsx]
2024-05-27 Hardware files uploaded
    [W0003510-00-001-2CHG sonic concepts 54.SLDASM, W0003510-00-001-2CHG sonic concepts 54.STEP, W0003510-00-002-4CH Sonic Concepts Transducer holder 72.SLDASM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]
2024-06-13 updated IGT 32 ch. configs for disabling current limit
2024-07-26 acquisition rewrite
    - sync logger and config of fds with charac.
    - improve robustness: cannot read ini then use default
    - improve and rename boolean perform all sequences
    - remove psychopy dependency
    - remove homing and connecting to ds each sequence
    - rewrite acquisition
2024-07-29 add picoscope and hydrophone choice to gui, bug fixes
    - make functions private if applicable
    - improve acquisition.py based on run code analysis
    - IGT fix: add delay of 20 ms between send and execute of IGT to solve board issues. In a bit we receive a firmware update
    - add picoscope choice to front-end and save it in ini
    - add hydrophone choice to front-end and save it in ini
    - fix lifting of gui
    - fix error with ds com
    - improve logging neurofus which phase table is used
    [acquisition.py, characterization_config.ini, characterization_input_cache.ini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]
2024-07-30 Increase flexibility, improve sham feature
    - able to choose sham degree per sequence
    - add tag to protocol excel to be able to add details to logging/save in ini file
    - logging of power will be adapted based on chosen equipment, same is done for transducer steering_info (only for IGT required)
    - more parameters are saved in the ini like ACD processing parameters
    - maximum amount of file number added to config
    - hydrophone datasheet added to config, so sensitivity based on used frequency is logged in ini as well
    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
    [CTX-250-001 - TPO-105-010 - Steer Table.xlsx, CTX-250-001 - TPO-203-035 - Steer Table.xlsx, CTX-250-009 - TPO-105-010 - Steer Table.xlsx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]
2024-07-31 Addition of IGT pressure compensation compatibility
2024-08-09 small GUI error message fix
    [acquisition.py]
2024-08-19 initial test scripts, bug fixes
    [acquisition.py, sequence.py, test_acquisition.py]
2024-08-21 IGT prepare/sendSequence() fix, remove extra seq logging
    prepareSequence always needs to happen before sendSequence so all channels will be synchronized.
    [acquisition.py, sequence.py, test_acquisition.py]
2024-09-18 Update HGL-0200 Calibration datasheet.xlsx
    [HGL-0200 Calibration datasheet.xlsx]
2024-09-18 bug fixing merge configs + oper_freq
    [acquisition.py]
2024-09-18 Renamed and added hydrophones calibration data
    Changed the naming of the hydrophones and added the calibration xls sheet (blank up till now, but enables measurements)
    [HGL 0200 SN2845 Calibration datasheet.xlsx, HNR 0500 SN2439 Calibration datasheet.xlsx, OLD_before_26-9-2024_HGL-0200 Calibration datasheet.xlsx]
2024-09-19 Bug fix oper_freq and pulse_dur unit
    Update create config with addition of new hydrophone
    [acquisition.py, characterization_config.ini, input_parameters.py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]
2024-09-20 Unit fix global power and pulse dur
    [acquisition.py, characterization_input_cache.ini, sequence.py]
2024-09-20 bug fixing acoustical alignment
    [acquisition.py]
2024-10-09 dephasing is none fix
    [sequence.py]
2024-10-25 add coeff logging + solve logging bug
    [acquisition.py]
2024-11-06 first set focus, then power
2024-11-18 new ylim acous. align + diff excel focus input
    [isppa_to_global_power_template.xlsx, template_protocol_input.xlsx]
2024-11-18 improved template + power assignment
    [template_protocol_input.xlsx]
2024-11-29 #37, #34 and other
    - plot history
    - save average in cache
    - solve error when closing dialogs
    [acoustical_alignment.py, acquisition.py, characterization_config.ini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]
2024-12-12 new release debugging
    [HGL 0200 SN3030 Calibration datasheet.xlsx]
2024-12-13 Fix empty nslices_nrows_ncolumns in ini
    [acoustical_alignment.py, acquisition.py]
2024-12-18 close logger + solve stuck console + x button action #25
    [acquisition.py]
2025-01-08 #45 bring dephasing/setting phases to front-end #45
    [template_protocol_input.xlsx]
2025-01-10 debugging for new release
    [template_protocol_input.xlsx]
2025-01-13 Save IGT phases in ini + topmost dialog fix
    [acquisition.py, characterization_input_cache.ini]
2025-01-31 #58 Handle setting amplitude or voltage per element for IGT equipment
    [template_protocol_input.xlsx]
2025-02-06 Rewritten PCD - initial setup utils
    - Updated hydrophone sheets - wrong unit
    - acquire_data not private anymore
    - remove bugs
    [HGL 0200 SN2845 Calibration datasheet.xlsx, HGL 0200 SN3030 Calibration datasheet.xlsx]
2025-02-07 Fix acoustic align. round down issues
    [acoustical_alignment.py]
2025-02-07 pcd IGT log path bugfix
    [acquisition.py, pcd_acquisition.py]
2025-02-10 fix ampl in pcd title
    [pcd_acquisition.py]
2025-02-21 Improve logging + expand config
    - no empty sys.exit
    - improved usage of loglevels
    - removed print statements
    - config is extracted from configfile with default value on the side
    - new additions to the config
2025-03-27 version number from scripts removed + bug fixes
    [acoustical_alignment.py, acquisition.py, characterization_input_cache.ini]
2025-03-28 not compatible with handshake
    [acquisition.py]
2025-04-25 temporary pcd focus out of range fix
    [pcd_acquisition.py]
2025-05-13 SC bug fix power extraction
    [acquisition.py, input_parameters.py]
2025-07-04 read pressure bugfix
2025-08-12 current setup
2025-09-03 enable engineering mode to use volt and ampl
2025-10-15 Development version data analysis
    [2024100030-1-Data.xlsx]
2026-04-23 Allow lateral processing (no filtering)
2026-06-04 bugfix save com driving system
    [input_parameters.py]
2026-06-10 bug usage other pico-channel
    [acquisition.py]
2026-07-29 Spatial filtering of lateral and elevational line scans
2026-08-24 [ENHANCEMENT] - add postprocessing scripts to check PCD baseline drift and compute new baselines
    [pcd_check_baseline_drift.py, pcd_compute_new_baseline.py]
